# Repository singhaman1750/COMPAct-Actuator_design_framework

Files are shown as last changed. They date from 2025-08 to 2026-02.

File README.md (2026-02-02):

# COMPAct: Actuator design framework

This repository provides an implementation of the paper:

<td style="padding:20px;width:75%;vertical-align:middle">
      <a href="https://arxiv.org/abs/2510.07197" target="_blank">
      <b> COMPAct: Computational Optimization and Automated Modular design of Planetary Actuators </b>
      </a>
      <br>
      <a href="https://singhaman1750.github.io/" target="_blank">Aman Singh</a>, <a href="https://www.linkedin.com/in/deepak-kapa-iitr26/" target="_blank">Deepak Kapa</a>, <a href="https://www.linkedin.com/in/suryank-joshi/" target="_blank">Suryank Joshi</a>, and <a href="https://www.shishirny.com/" target="_blank">Shishir Kolathaya</a>
      <br>
      <em>IEEE International Conference on Robotics and Automation</em>, 2026
      <br>
      <a href="https://youtu.be/99zOKgxsDho?si=5hyMySFOMPunLLCl">Video-Overview</a>
    <br>
</td>

<br>

----

This framework provides the following features:
1. **Optimize planetary gearbox** parameters for a **given motor** across the following gearbox types:
      - Single Stage Planetary Gearbox (SSPG),
      - Compound Planetary Gearbox (CPG),
      - Wolfrom Planetary Gearbox (3K)(WPG), and
      - Double Stage Planetary Gearbox (DSPG).

2. Perform multi-objective optimization to **minimize actuator mass** and **axial width** while **maximizing efficiency**.
3. **Automatically generate parametric actuator CAD** from optimization results, enabling direct **3D printing without manual redesign**.

----

## ✅ Supported Hardware

### Supported Motors
| Motor Code | Description |
| :--- | :--- |
| **U8** | T-motor U8 |
| **U10** | T-motor U10+ |
| **U12** | T-motor U12 |
| **MN8014** | T-motor MN8014 |
| **VT8020** | Vector Techniques 8020 |
| **MAD_M6C12**| MAD Components M6C12 |

### Supported Gearbox Topologies
| Type | Description |
| :--- | :--- |
| **sspg** | Single-Stage Planetary Gearbox |
| **cpg** | Compound Planetary Gearbox |
| **wpg** | Wolfrom Planetary Gearbox (3K) |
| **dspg** | Double-Stage Planetary Gearbox |

---

## 💻 Setup & Requirements

### System Requirements
* **Python 3.x**
* **SolidWorks 2024** (or higher) – *Required for CAD automation features.*

### Recommended Terminal
* **Windows:** [Git Bash](https://git-scm.com/downloads) is highly recommended.
* **Linux/macOS:** Default terminal.

### 1. Installation
Clone the repository and install the dependencies:

```bash
# Clone the repository
git clone https://github.com/singhaman1750/COMPAct-Actuator_design_framework.git

# Enter the directory
cd COMPAct-Actuator_design_framework 

# Install required packages
pip install numpy matplotlib pandas
```

### 2. Extract CAD Files (Optional)
Due to file size limits, CAD files are zipped. You must extract them before running the framework.

**NOTE:** _If you only need the optimized gear parameters (teeth count, module, etc.), you can skip this step. Extraction is only required if you intend to use the **automated 3D modeling**._

1.  Navigate to the `CADs` directory.
2.  Inside each gearbox folder (e.g., `CADs/SSPG/`), unzip the archive (e.g., `sspg_actuator.zip`) into the **same directory**.

Your directory structure should look like this after extraction:
```text
COMPAct-Actuator_design_framework/
└── CADs/
    ├── SSPG/sspg_actuator/sspg_actuator/...
    ├── CPG/cpg_actuator/cpg_actuator/...
    ├── DSPG/dspg_actuator/dspg_actuator/...
    └── WPG/wpg_actuator/wpg_actuator/...
```

---

## 🚀 Usage

### Step 1: Run Optimization
Run the Python script from the root directory to generate optimal gear parameters.

**Syntax:**
```bash
python actOpt.py <motor> <gearbox> <ratio>
```
* **`<motor>`**: U8, U10, U12, MN8014, VT8020, MAD_M6C12
* **`<gearbox>`**: sspg, cpg, dspg, wpg
* **`<ratio>`**: Must be a value > 2.

**Example:**
To optimize a **T-motor U8** with a **Single-Stage Planetary Gearbox** and a **ratio of 6.5**:

```bash
python actOpt.py U8 sspg 6.5
```

### Step 2: View Results
The script will output the optimal geometric parameters directly in the terminal:

```text
Running optimization:
  Motor       : U8
  Gearbox     : sspg
  Gear Ratio  : 6.5
Time taken: 0.0196 sec
Optimization Completed.
-------------------------------
Optimal Parameters:
Number of teeth: Sun(Ns): 23 , Planet(Np): 52 , Ring(Nr): 127 , Module(m): 0.6 , NumPlanet(n_p): 3
---
Gear Ratio(GR): 6.52 : 1
-------------------------------
```

Detailed parameter files (used by SolidWorks) are automatically generated in the following locations:

* **SSPG:** `CADs/SSPG/sspg_equations.txt`
* **CPG:** `CADs/CPG/cpg_equations.txt`
* **DSPG:** `CADs/DSPG/dspg_equations.txt`
* **WPG:** `CADs/WPG/wpg_equations.txt`

### Step 3: CAD Automation
**NOTE:** _If you skipped the CAD extraction, you can stop at Step 2._

1.  Open **SolidWorks**.
2.  Open the assembly file (`.SLDASM`) for your specific gearbox type:
    * **SSPG:** `CADs/SSPG/sspg_actuator/sspg_actuator/sspg_actuator.SLDASM`
    * *(Paths for CPG, DSPG, and WPG follow the same folder pattern)*
3.  Click the **Rebuild** (Traffic Light) icon.
4.  The 3D model will automatically update to reflect the calculated parameters.

### Step 4: Manufacturing
* **3D Printing:** Export the updated plastic parts to `.STL` format.
* **Bearings:** Check the updated CAD model to identify which standard bearings are required for your specific configuration.

---

## 📄 Citation

If you use this framework in your research, please cite:

```bibtex
@misc{singh2025compact,
      title={COMPAct: Computational Optimization and Automated Modular design of Planetary Actuators}, 
      author={Aman Singh and Deepak Kapa and Suryank Joshi and Shishir Kolathaya},
      year={2025},
      eprint={2510.07197},
      archivePrefix={arXiv},
      primaryClass={cs.RO},
      url={[https://arxiv.org/abs/2510.07197](https://arxiv.org/abs/2510.07197)}, 
}
```

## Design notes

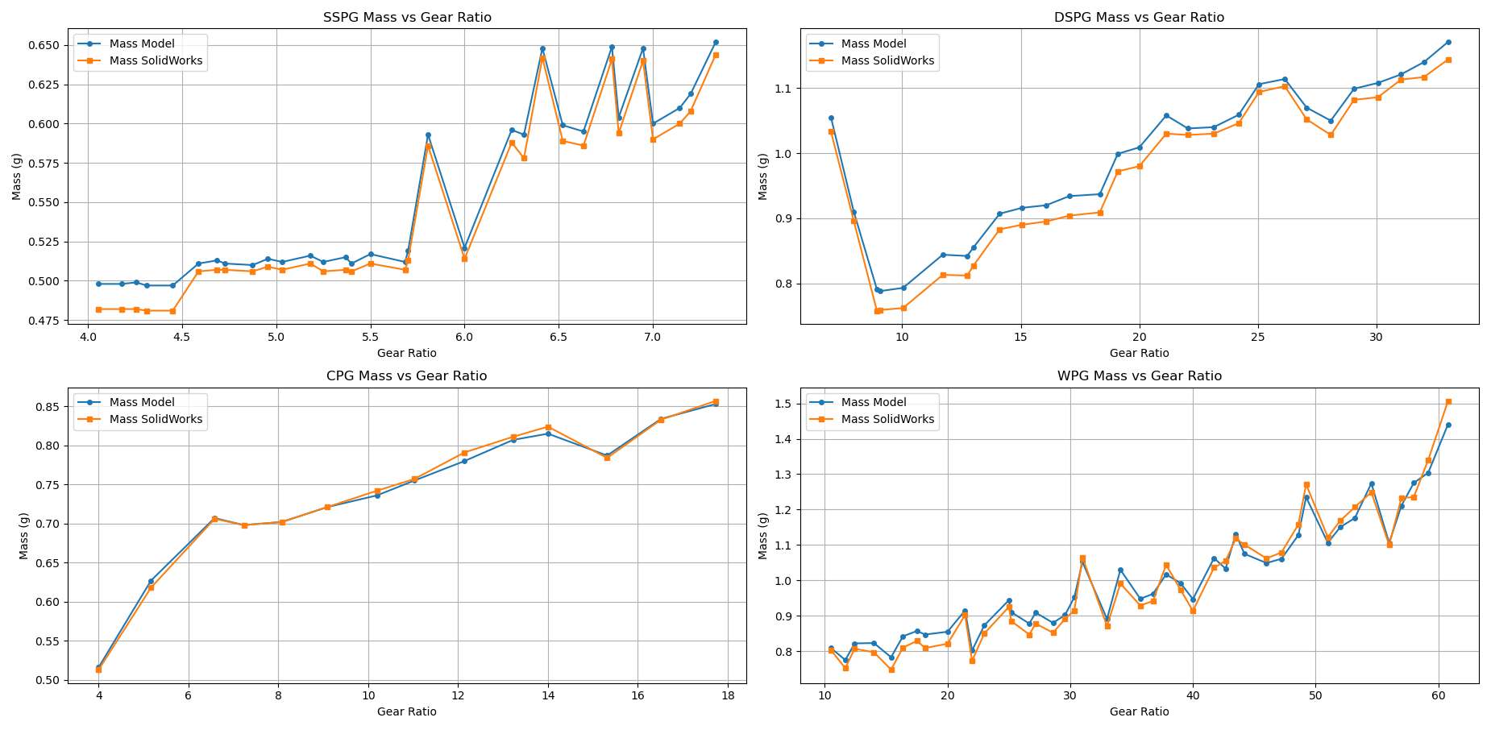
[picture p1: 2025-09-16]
plots/simulation/mass_comparison/mass_comparison.png

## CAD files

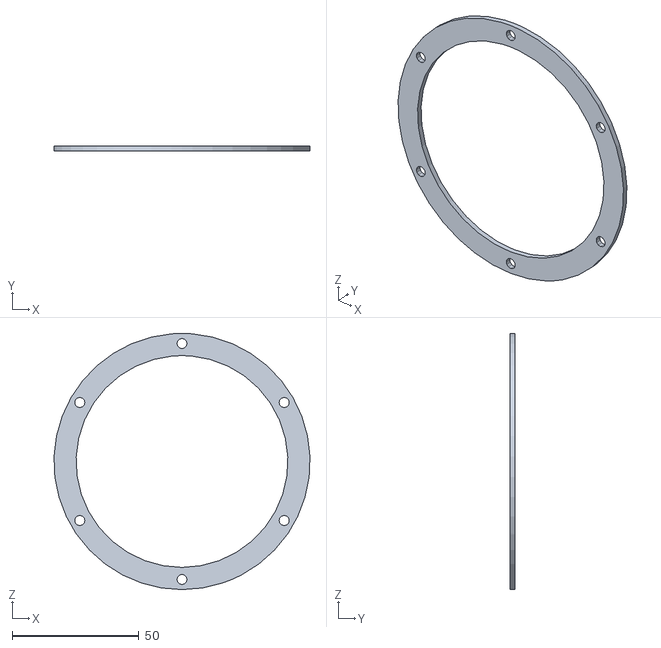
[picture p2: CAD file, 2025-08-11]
STLs used for testing/cpg_14/cpg_bearing_retainer.STL
100.9 x 2.00 x 101.0

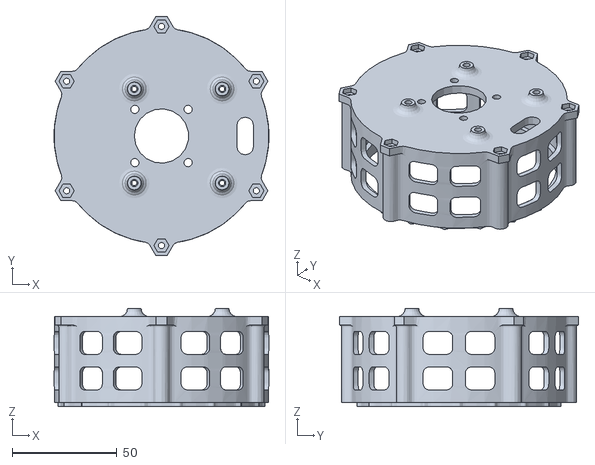
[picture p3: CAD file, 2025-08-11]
STLs used for testing/sspg_7.2/sspg_motor_casing.STL
102.6 x 114.3 x 47.0

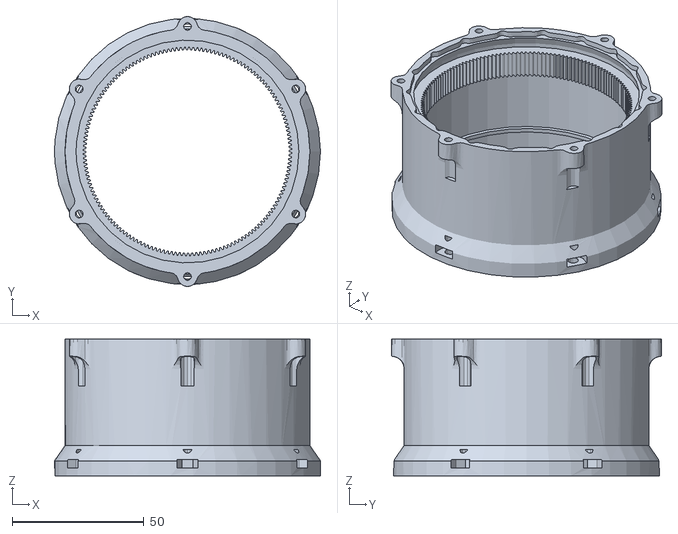
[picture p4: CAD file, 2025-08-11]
STLs used for testing/wpg_16/wpg_gearbox_casing.STL
101.0 x 102.5 x 51.9

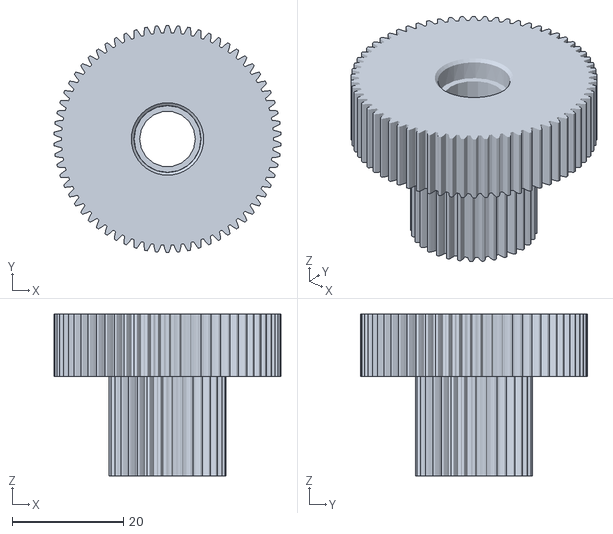
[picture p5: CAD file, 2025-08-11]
STLs used for testing/cpg_14/cpg_planet.STL
40.8 x 40.8 x 29.1

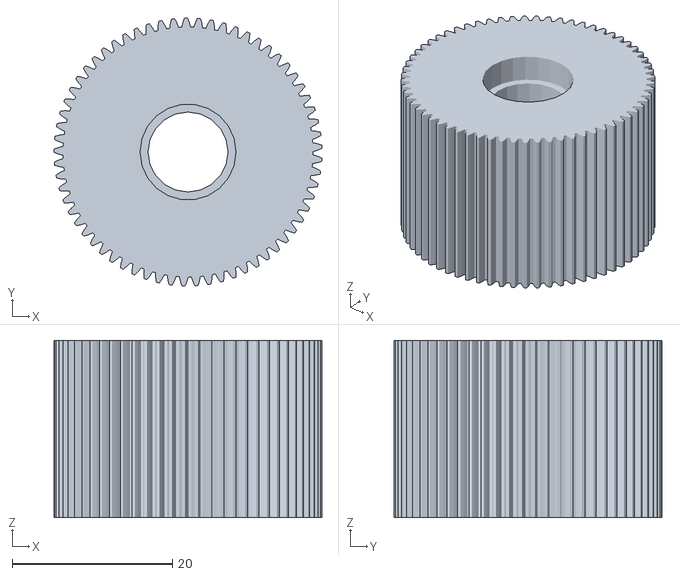
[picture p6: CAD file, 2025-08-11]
STLs used for testing/sspg_7.2/sspg_planet.STL
33.5 x 33.5 x 22.1

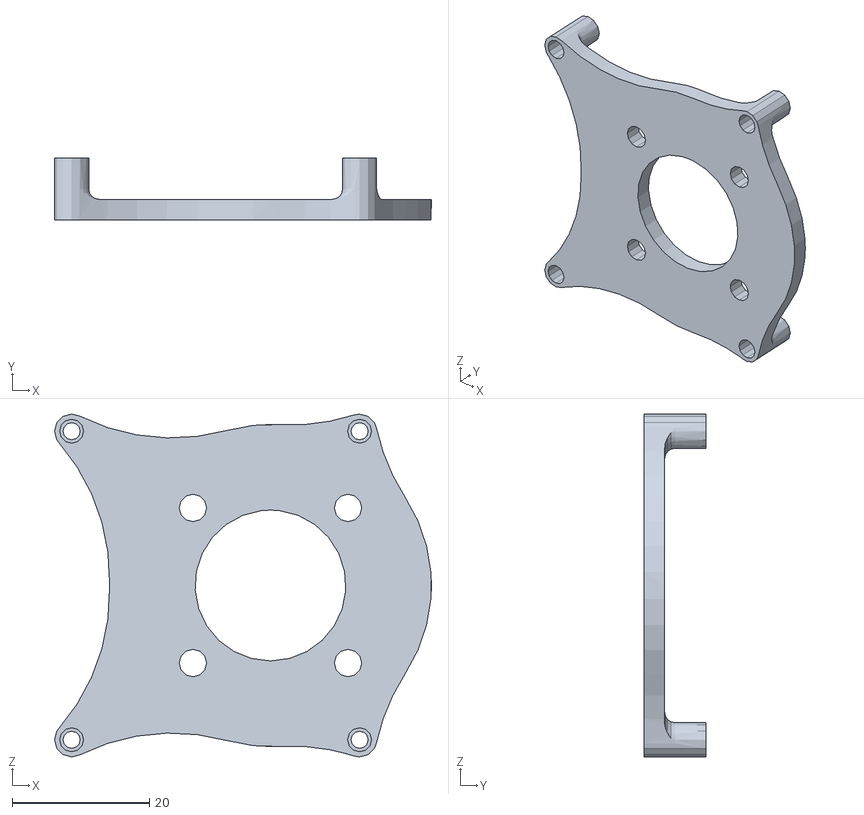
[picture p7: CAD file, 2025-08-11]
STLs used for testing/wpg_16/wpg_driver_mount.STL
55.0 x 9.00 x 50.0

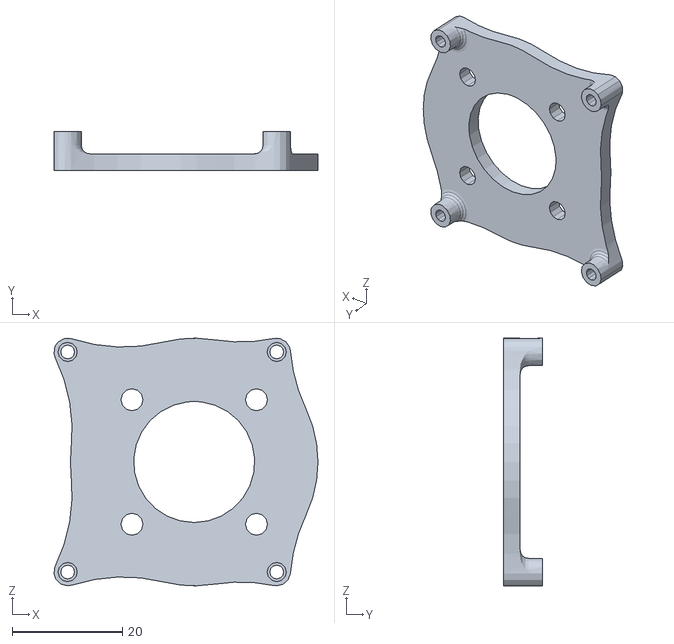
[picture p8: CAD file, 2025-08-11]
STLs used for testing/cpg_14/cpg_driver_mount.STL
48.0 x 7.00 x 45.0

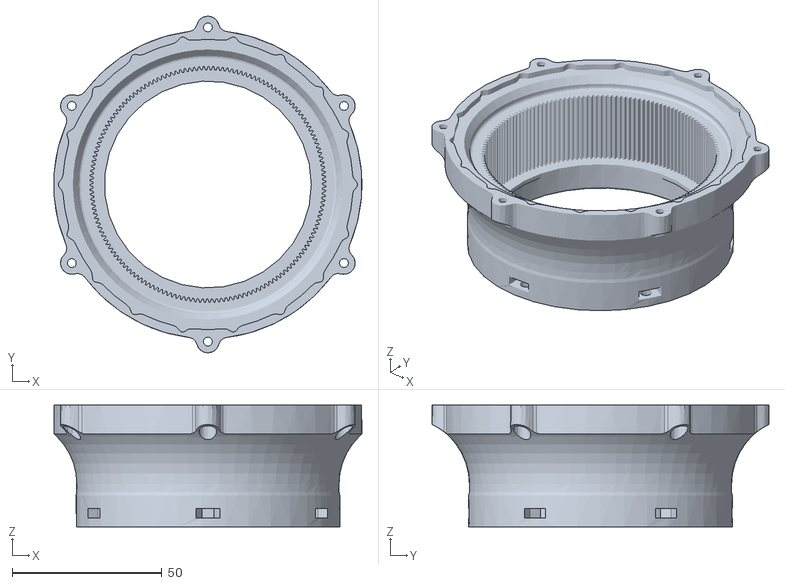
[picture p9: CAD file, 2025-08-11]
STLs used for testing/sspg_7.2/sspg_gearbox_casing.STL
102.7 x 112.3 x 40.6

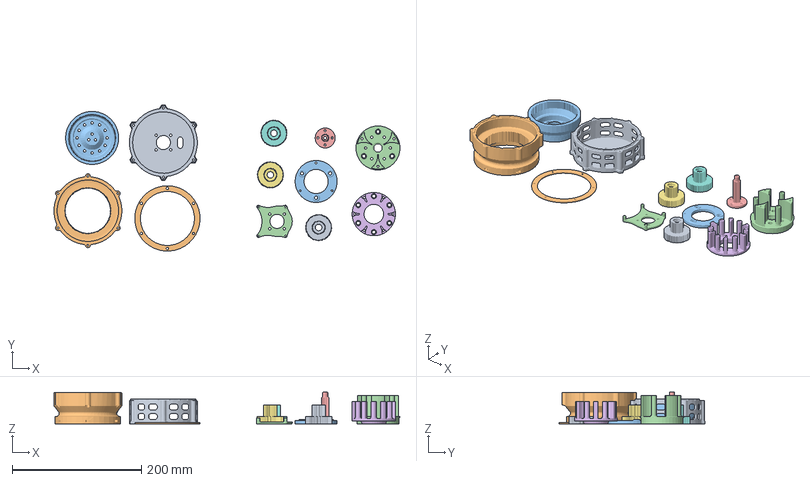
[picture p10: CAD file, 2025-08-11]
STLs used for testing/wpg_16/wpg_carrier.3mf
534.5 x 225.9 x 49.1 mm
cpg_motor_casing.STL
cpg_gearbox_casing.STL
wpg_small_ring.STL
cpg_carrier.STL
cpg_sun.STL
wpg_carrier.STL
cpg_planet.STL x 3
cpg_bearing_retainer.STL
cpg_sec_carrier.STL
wpg_driver_mount.STL

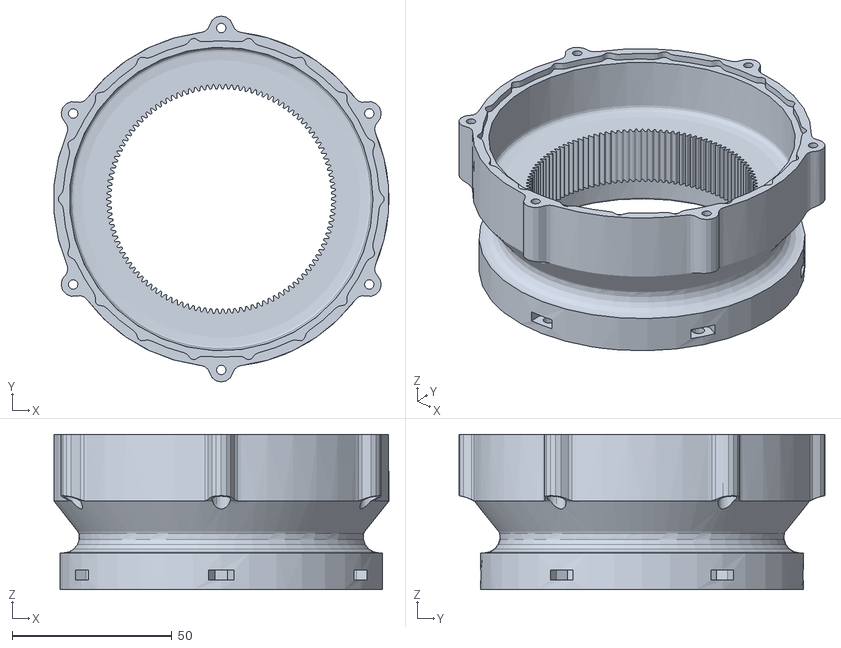
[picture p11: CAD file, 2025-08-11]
STLs used for testing/cpg_14/cpg_gearbox_casing.STL
104.8 x 114.5 x 48.6

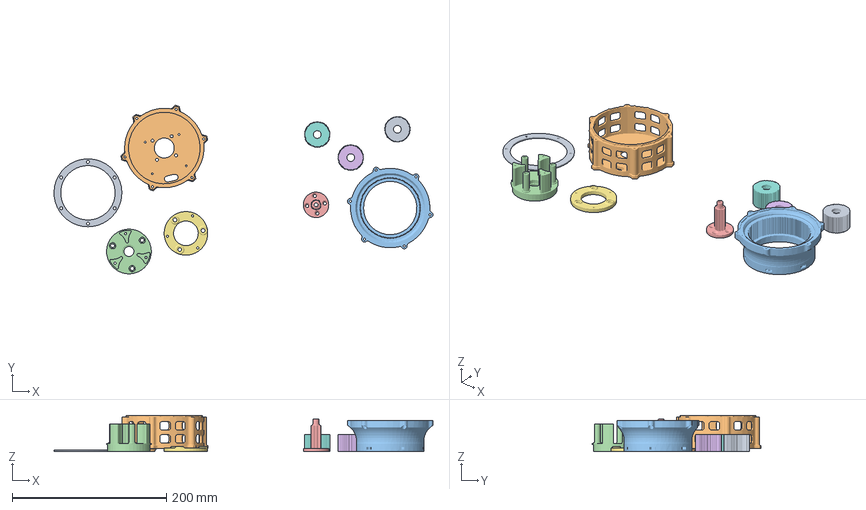
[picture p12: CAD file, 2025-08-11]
STLs used for testing/sspg_7.2/sspg_bearing_retainer.3mf
490.9 x 218.3 x 47.0 mm
sspg_bearing_retainer.STL
sspg_motor_casing.STL
sspg_gearbox_casing.STL
sspg_carrier.STL
sspg_sun.STL
sspg_planet.STL x 3
sspg_sec_carrier.STL

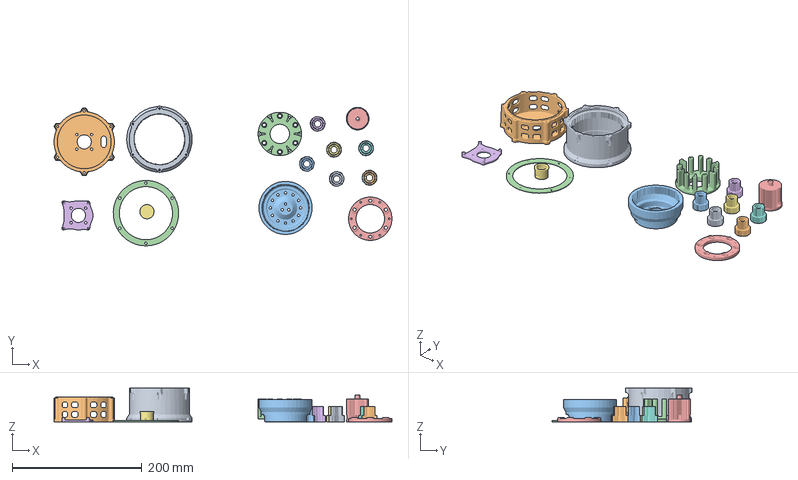
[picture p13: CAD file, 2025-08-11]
STLs used for testing/wpg_16/wpg_bearing_retainer.3mf
521.2 x 215.6 x 51.9 mm
wpg_gearbox_casing.STL
wpg_motor_casing.STL
wpg_small_ring.STL
wpg_carrier.STL
wpg_sun.STL
wpg_planet.STL x 6
wpg_bearing_retainer.STL
wpg_sec_carrier.STL
wpg_driver_mount.STL
wpg_small_ring_bearing_shaft.STL

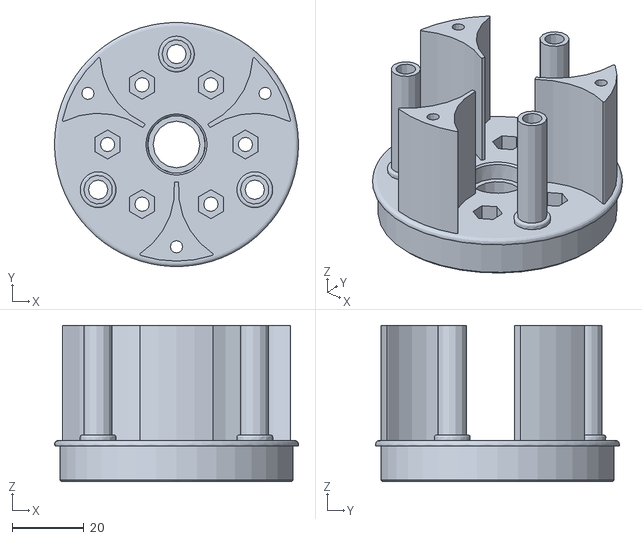
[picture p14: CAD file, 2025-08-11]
STLs used for testing/cpg_14/cpg_carrier.STL
68.0 x 67.9 x 43.6

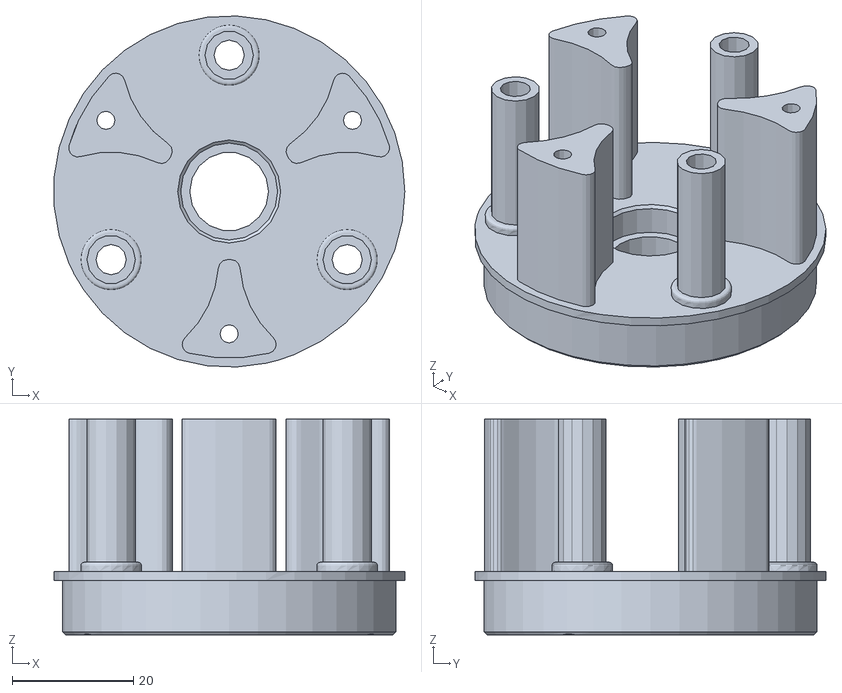
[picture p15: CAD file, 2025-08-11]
STLs used for testing/sspg_7.2/sspg_carrier.STL
57.9 x 57.9 x 35.6

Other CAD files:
STLs used for testing/wpg_16/wpg_motor_casing.STL
STLs used for testing/cpg_14/cpg_sun.STL
STLs used for testing/sspg_7.2/sspg_carrier_updated.STL
STLs used for testing/wpg_16/wpg_sec_carrier.STL
STLs used for testing/cpg_14/cpg_motor_casing.STL
STLs used for testing/cpg_14/cpg_sec_carrier.STL
STLs used for testing/sspg_7.2/sspg_bearing_retainer.STL
STLs used for testing/sspg_7.2/sspg_sec_carrier.STL
STLs used for testing/sspg_7.2/sspg_sun.STL
STLs used for testing/wpg_16/wpg_bearing_retainer.STL
STLs used for testing/wpg_16/wpg_carrier.STL
STLs used for testing/wpg_16/wpg_planet.STL
STLs used for testing/wpg_16/wpg_small_ring.STL
STLs used for testing/wpg_16/wpg_small_ring_bearing_shaft.STL
STLs used for testing/wpg_16/wpg_sun.STL

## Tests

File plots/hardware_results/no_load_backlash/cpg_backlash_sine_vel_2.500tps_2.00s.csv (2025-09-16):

time_s | odrive_pos_rad | output_pos_rad | diff_rad | odrive_disp_rad | output_disp_rad | motor_on_output_side_rad | backlash_rad
4.613474 | 25.115614 | 3.07218 | 22.043434 | -4.880306999999998 | -0.37064799999999964 | -0.34859335714285705 | 0.022054642857142592
4.614222 | 25.116248 | 3.071413 | 22.044835 | -4.879673 | -0.3698809999999999 | -0.34854807142857147 | 0.021332928571428433
4.617824 | 25.11573 | 3.071797 | 22.043933 | -4.880191 | -0.37026499999999984 | -0.3485850714285714 | 0.02167992857142842
4.620985 | 25.115903 | 3.071413 | 22.04449 | -4.880018 | -0.3698809999999999 | -0.3485727142857143 | 0.021308285714285613
4.620985 | 25.115903 | 3.071413 | 22.04449 | -4.880018 | -0.3698809999999999 | -0.3485727142857143 | 0.021308285714285613
4.627344 | 25.116594 | 3.071797 | 22.044797 | -4.879327 | -0.37026499999999984 | -0.34852335714285715 | 0.021741642857142696
4.630123 | 25.116855 | 3.071413 | 22.045442 | -4.879065999999998 | -0.3698809999999999 | -0.34850471428571417 | 0.021376285714285737
4.633402 | 25.117673 | 3.071413 | 22.04626 | -4.878247999999999 | -0.3698809999999999 | -0.34844628571428565 | 0.02143471428571425
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

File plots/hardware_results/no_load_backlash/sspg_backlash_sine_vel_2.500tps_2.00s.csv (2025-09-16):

time_s | odrive_pos_rad | output_pos_rad | diff_rad | odrive_disp_rad | output_disp_rad | motor_on_output_side_rad | backlash_rad
4.357542 | -4.761945 | 3.243602 | -8.005548 | 0.0 | -0.0 | 0.0 | 0.0
4.35977 | -4.76181 | 3.243219 | -8.005029 | 0.00013500000000021828 | 0.00038300000000024426 | 1.8750000000030315e-05 | -0.00036425000000021396
4.363282 | -4.762313 | 3.243219 | -8.005532 | -0.00036799999999992394 | 0.00038300000000024426 | -5.1111111111100544e-05 | -0.0004341111111113448
4.367624 | -4.762277 | 3.243602 | -8.005879 | -0.000332000000000221 | -0.0 | -4.6111111111141805e-05 | -4.6111111111141805e-05
4.369163 | -4.762479 | 3.243602 | -8.006081 | -0.0005340000000000344 | -0.0 | -7.416666666667145e-05 | -7.416666666667145e-05
4.372204 | -4.762899 | 3.243602 | -8.006501 | -0.0009540000000001214 | -0.0 | -0.00013250000000001685 | -0.00013250000000001685
4.374977 | -4.761776 | 3.243986 | -8.005762 | 0.00016899999999964166 | -0.00038399999999993994 | 2.347222222217245e-05 | 0.0004074722222221124
4.378174 | -4.762672 | 3.243986 | -8.006658 | -0.0007270000000003662 | -0.00038399999999993994 | -0.00010097222222227309 | 0.00028302777777766686
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

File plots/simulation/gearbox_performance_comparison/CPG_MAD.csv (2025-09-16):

iter | gearRatio | moduleBig | moduleSmall | Ns | NpBig | NpSmall | Nr | numPlanet | fwSunMM | fwPlanetBigMM | fwPanetSmallMM | fwRingMM | mass | eff | peakTorque | Cost | Torque_Density | Outer_Bearing_mass | Actuator_width
97 | 4.0 | 0.5 | 0.5 | 40 | 40 | 40 | 120 | 4 | 4.242 | 4.242 | 3.785 | 3.785 | 0.516 | 0.963 | 9.218 | 0.1961486165728641 | 17.864 | 0.05 | 64.52710222773382
107 | 5.1652892561983474 | 0.5 | 0.5 | 44 | 56 | 44 | 144 | 4 | 3.707 | 3.707 | 4.316 | 4.316 | 0.627 | 0.965 | 11.904 | 0.30162087343088784 | 18.986 | 0.103 | 67.52308242315834
94 | 6.58 | 0.6 | 0.6 | 40 | 54 | 30 | 124 | 4 | 2.9 | 2.9 | 5.155 | 5.155 | 0.707 | 0.955 | 15.164 | 0.4076484148014552 | 21.448 | 0.134 | 67.55542476677977
77 | 7.230392156862743 | 0.9 | 0.9 | 18 | 41 | 34 | 93 | 3 | 5.093 | 5.093 | 4.304 | 4.304 | 0.698 | 0.941 | 16.663 | 0.6956549007050923 | 23.872 | 0.128 | 68.8970131340608
72 | 8.07738095238095 | 0.9 | 0.9 | 18 | 41 | 28 | 87 | 3 | 5.093 | 5.093 | 5.541 | 5.541 | 0.702 | 0.936 | 18.615 | 0.9569674281019194 | 26.517 | 0.128 | 70.13379559147111
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

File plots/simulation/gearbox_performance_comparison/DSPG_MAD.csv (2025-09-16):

iter | gearRatio | module1 | module2 | Ns1 | Np1 | Nr1 | numPlanet1 | Ns2 | Np2 | Nr2 | numPlanet2 | fwSun1MM | fwPlanet1MM | fwRing1MM | fwSun2MM | fwPlanet2MM | fwRing2MM | mass | eff | peakTorque | Cost | Torque_Density | Outer_Bearing_mass_stg1 | Outer_Bearing_mass_stg2 | Actuator_width
7 | 6.998939554612938 | 0.5 | 0.5 | 82 | 28 | 138 | 4 | 92 | 28 | 148 | 3 | 1.873 | 8.0 | 8.0 | 5.869 | 8.0 | 8.0 | 1.055 | 0.929 | 16.13 | 2.3968831573856804 | 15.28909952606635 | 0.128 | 0.134 | 95.0
15 | 7.960199004975124 | 0.5 | 0.5 | 67 | 29 | 125 | 3 | 72 | 28 | 128 | 4 | 3.148 | 8.0 | 8.0 | 6.244 | 8.0 | 8.0 | 0.91 | 0.926 | 18.345 | 2.2577695520571113 | 20.159340659340657 | 0.103 | 0.103 | 95.0
11 | 8.933002481389579 | 0.5 | 0.5 | 52 | 28 | 108 | 4 | 62 | 28 | 118 | 4 | 3.161 | 8.0 | 8.0 | 7.952 | 8.0 | 8.0 | 0.791 | 0.921 | 20.587 | 2.148107075478584 | 26.02654867256637 | 0.05 | 0.081 | 91.0
15 | 9.058064516129033 | 0.5 | 0.5 | 50 | 28 | 106 | 3 | 62 | 28 | 118 | 4 | 4.413 | 8.0 | 8.0 | 8.064 | 8.064 | 8.064 | 0.788 | 0.921 | 20.875 | 2.158341069914128 | 26.491116751269033 | 0.05 | 0.081 | 91.0636744861659
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

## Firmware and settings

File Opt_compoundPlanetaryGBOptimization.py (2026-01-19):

import sys
import numpy as np
from ActuatorAndGearbox import motor
from ActuatorAndGearbox import material
from ActuatorAndGearbox import compoundPlanetaryGearbox
from ActuatorAndGearbox import compoundPlanetaryActuator
from ActuatorAndGearbox import optimizationCompoundPlanetaryActuator
import os
import json

#--------------------------------------------------------
# Importing motor data
#--------------------------------------------------------
# Get the current directory
current_dir = os.path.dirname(__file__)

# Build the file path
config_path = os.path.join(current_dir, "config_files/config.json")
cpg_params_path = os.path.join(current_dir, "config_files/cpg_params.json")

# Load the JSON file
with open(config_path, "r") as config_file:
    config_data = json.load(config_file)

with open(cpg_params_path, "r") as cpg_params_file:
    cpg_params = json.load(cpg_params_file)

#---------------------------------------------------
# Transferring relevant data to individual variables
#---------------------------------------------------
motor_data          = config_data["Motors"]
material_properties = config_data["Material_properties"]

Gear_standard_parameters = config_data["Gear_standard_parameters"]
Lewis_params             = config_data["Lewis_params"]
MIT_params               = config_data["MIT_params"]

Steel    = material_properties["Steel"]
Aluminum = material_properties["Aluminum"]
PLA      = material_properties["PLA"]

cpg_design_params       = cpg_params["cpg_3DP_design_parameters"]
cpg_optimization_params = cpg_params["cpg_optimization_parameters"]

motor_driver_data = config_data["Motor_drivers"]

#--------------------------------------------------------
# Motors Drivers
#--------------------------------------------------------
Motor_Driver_Moteus_params    = motor_driver_data["Moteus"]
Motor_Driver_OdrivePro_params = motor_driver_data["OdrivePro"]

#--------------------------------------------------------
# Motors
#--------------------------------------------------------
# T motor U8
MotorU8_Kv                         = motor_data["MotorU8_framed"]["Kv"]                   # rpm/V
MotorU8_maxContinuousCurrent       = motor_data["MotorU8_framed"]["maxContinuousCurrent"] # A

MotorU8_maxTorque                  = MotorU8_maxContinuousCurrent / (MotorU8_Kv * 2 * np.pi / 60)
MotorU8_power                      = motor_data["MotorU8_framed"]["power"]                 # W 
MotorU8_ratedVoltage               = motor_data["MotorU8_framed"]["ratedVoltage"]   
MotorU8_maxMotorAngVelRPM          = MotorU8_Kv * MotorU8_ratedVoltage # RPM 
MotorU8_mass                       = motor_data["MotorU8_framed"]["mass"]                  # kg 
MotorU8_dia                        = motor_data["MotorU8_framed"]["dia"]                   # mm 
MotorU8_length                     = motor_data["MotorU8_framed"]["length"]                # mm
MotorU8_motor_mount_hole_PCD       = motor_data["MotorU8_framed"]["motor_mount_hole_PCD"]
MotorU8_motor_mount_hole_dia       = motor_data["MotorU8_framed"]["motor_mount_hole_dia"]
MotorU8_motor_mount_hole_num       = motor_data["MotorU8_framed"]["motor_mount_hole_num"]
MotorU8_motor_output_hole_PCD      = motor_data["MotorU8_framed"]["motor_output_hole_PCD"]
MotorU8_motor_output_hole_dia      = motor_data["MotorU8_framed"]["motor_output_hole_dia"]
MotorU8_motor_output_hole_num      = motor_data["MotorU8_framed"]["motor_output_hole_num"]
MotorU8_wire_slot_dist_from_center = motor_data["MotorU8_framed"]["wire_slot_dist_from_center"]
MotorU8_wire_slot_length           = motor_data["MotorU8_framed"]["wire_slot_length"]
MotorU8_wire_slot_radius           = motor_data["MotorU8_framed"]["wire_slot_radius"]

# U10 Motor
MotorU10_Kv                         = motor_data["MotorU10_framed"]["Kv"]                   # rpm/V
MotorU10_maxContinuousCurrent       = motor_data["MotorU10_framed"]["maxContinuousCurrent"] # A

MotorU10_maxTorque                  = MotorU10_maxContinuousCurrent / (MotorU10_Kv * 2 * np.pi / 60)
MotorU10_power                      = motor_data["MotorU10_framed"]["power"]                  # W
MotorU10_ratedVoltage               = motor_data["MotorU10_framed"]["ratedVoltage"]   
MotorU10_maxMotorAngVelRPM          = MotorU10_Kv * MotorU10_ratedVoltage   # RPM
MotorU10_mass                       = motor_data["MotorU10_framed"]["mass"]                   # Kg 
MotorU10_dia                        = motor_data["MotorU10_framed"]["dia"]                    # mm
MotorU10_length                     = motor_data["MotorU10_framed"]["length"]                 # mm
MotorU10_motor_mount_hole_PCD       = motor_data["MotorU10_framed"]["motor_mount_hole_PCD"]
MotorU10_motor_mount_hole_dia       = motor_data["MotorU10_framed"]["motor_mount_hole_dia"]
MotorU10_motor_mount_hole_num       = motor_data["MotorU10_framed"]["motor_mount_hole_num"]
MotorU10_motor_output_hole_PCD      = motor_data["MotorU10_framed"]["motor_output_hole_PCD"]
MotorU10_motor_output_hole_dia      = motor_data["MotorU10_framed"]["motor_output_hole_dia"]
MotorU10_motor_output_hole_num      = motor_data["MotorU10_framed"]["motor_output_hole_num"]
MotorU10_wire_slot_dist_from_center = motor_data["MotorU10_framed"]["wire_slot_dist_from_center"]
MotorU10_wire_slot_length           = motor_data["MotorU10_framed"]["wire_slot_length"]
MotorU10_wire_slot_radius           = motor_data["MotorU10_framed"]["wire_slot_radius"]

# MN8014 Motor
MotorMN8014_Kv                         = motor_data["MotorMN8014_framed"]["Kv"]                   # rpm/V
MotorMN8014_maxContinuousCurrent       = motor_data["MotorMN8014_framed"]["maxContinuousCurrent"] # A
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

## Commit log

2025-06-07 #12 #11 #10 #9 #8 #6 working parametric sspg 3DP cad
    [sspg_actuator.SLDASM, sspg_bearing.SLDPRT, sspg_bearing_retainer.SLDPRT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]
2025-07-15 Added output hole PCD and output hole dia for all the motors in config.json file
2025-07-16 function for single optimal actuator is added
2025-07-17 Added nuts and bolts as a separate class
2025-07-17 working cpg
    [CPG_BRUTEFORCE_Lewis_U10.csv]
2025-07-18 Added mitGearWidth Calc and print_mass_of_parts_3DP functions in CPG
2025-07-18 connected to CPG design parameters to JSON files -- CPG uses MIT gear width calc -- Minor change in SSPG --
2025-07-18 fixed bugs in cpg gearing profile angles
2025-07-18 added genOptimalActuator to CPG
    [CPG_BRUTEFORCE_Lewis_U8.csv, CPG_BRUTEFORCE_MIT_MN8014.csv, CPG_BRUTEFORCE_MIT_U10.csv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]
2025-07-18 deleting the CPG and SSPG CAD files and only updating the Zip files
    [cpg_actuator.SLDASM, cpg_bearing.SLDPRT, cpg_bearing_retainer.SLDPRT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]
2025-07-21 Added the corrected optimization code for WPG with lewis theory
    [Opt_wolfromPlanetaryGBOptimization.py]
2025-07-22 bug fixes in mass model and contraints of WPG
    [Opt_compoundPlanetaryGBOptimization.py, Opt_wolfromPlanetaryGBOptimization.py]
2025-07-22 fixed set variables in WPG , wpg json file and switched to bearing_discrete
2025-07-29 Working DSPG framework and optimization
2025-08-03 Removed some code clutter in sspg, also added individual mass printing in wpg & dspg
2025-08-03 added new motors and bug fix in wpg params
    [Opt_singleStagePlanetaryGBOptimization.py, Opt_wolfromPlanetaryGBOptimization.py]
2025-08-04 added driver class and 3dp clearances
    [Opt_singleStagePlanetaryGBOptimization.py]
2025-08-06 added printing clearances and bug fixes
    [Opt_compoundPlanetaryGBOptimization.py, Opt_wolfromPlanetaryGBOptimization.py]
2025-08-07 3D printed results - wpg and cpg
    [CPG_BRUTEFORCE_MIT_MAD_M6C12.csv, WPG_BRUTEFORCE_MIT_MAD_M6C12.csv]
2025-08-07 some changes and bug fixes
    [CPG_BRUTEFORCE_Lewis_U10.csv, DSPG_BRUTEFORCE_Lewis_U10.csv]
2025-08-11 Added final STL of SSPG, WPG and CPG
    These stls are used for testing
    [cpg_bearing_retainer.STL, cpg_carrier.STL, cpg_driver_mount.STL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]
2025-08-31 added wpg actuator width
2025-08-31 added actuator width in dspg and also added the gen equation file new version in dspg
2025-09-04 added updated sspg actuator
2025-09-04 added updated WPG actuator design
2025-09-08 DSPG MAD_M6C12
    [DSPG_BRUTEFORCE_MIT_MAD_M6C12.csv]
2025-09-12 added sspg results with smaller step gear ratio
    [SSPG_BRUTEFORCE_MIT_MAD_M6C12.csv]
2025-09-13 Added cpg mad results
    [CPG_BRUTEFORCE_MIT_MAD_M6C12.csv]
2025-09-16 Fixing a bug that was not printing the Actuator width in results
    [Opt_doubleStagePlanetaryGBOptimization.py]
2025-09-16 adding latest results
    [CPG_BRUTEFORCE_MIT_U8.csv, DSPG_BRUTEFORCE_MIT_U8.csv, SSPG_BRUTEFORCE_MIT_MN8014.csv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]
2025-09-16 Added mass comparison data and plots
    [3DP_mass_comparison_cpg.csv, 3DP_mass_comparison_dspg.csv, 3DP_mass_comparison_sspg.csv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]
2025-09-16 changed the name of mass comparison file
    [3DP_mass_comparison_cpg.csv, 3DP_mass_comparison_dspg.csv, 3DP_mass_comparison_sspg.csv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]
2025-09-16 changed the name of the gearbox_performance_comparison
    [CPG_MAD.csv, DSPG_MAD.csv, SSPG_MAD.csv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]
2025-09-16 Added run_all.sh file -- runs all the gearboxes for all the motors and saves the results
2025-09-16 added sspg data power eff and plots
    [1.00_10.csv, 1.00_20.csv, 1.00_30.csv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]
2025-09-16 added CPG power efficiency data
    [1.00_10.csv, 1.00_20.csv, 1.00_30.csv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]
2025-09-16 added no_load_backlash plotting files
    [cpg_backlash_sine_vel_2.500tps_2.00s.csv, sspg_backlash_sine_vel_2.500tps_2.00s.csv]
2026-01-17 added actuator optimization single terminal command with motor, gb_type, and gear_ratio input for SSPG
2026-01-19 made changes to run for a given motor, gearbox-type and for a given gearratio for all the types of gearbox
2026-01-30 Update README with optional CAD extraction note
    Clarify that CAD extraction is optional and provide notes on usage.
